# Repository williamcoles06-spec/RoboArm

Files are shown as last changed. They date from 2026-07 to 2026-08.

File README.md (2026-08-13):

# RoboArm

A 6-DOF robot arm I designed and built from scratch, running on a ROS 2 / MoveIt 2 stack.

## What this is

Six joints, each driven by a stepper motor with a custom gearbox: 27:1 cycloidal drives for the base, shoulder, and elbow, a 5:1 planetary drive for the forearm roll, and a 6:1 belt reduction into a bevel gear differential for the wrist pitch and roll. The structure is 3D printed in PLA, designed in Fusion 360.

Motion planning goes through MoveIt 2, but the hardware interface underneath it is custom. The stepper controllers (CANBUS Stepper boards, closed loop, daisy chained over CAN) don't fit cleanly into `ros2_control` on this setup, so I wrote a standalone ROS 2 node that acts as the `FollowJointTrajectory` action server MoveIt talks to directly. It turns planned trajectories into CAN bus position commands, verifies the arm actually reached each target using live encoder feedback, and publishes `/joint_states` back to MoveIt.

## Highlights

- Full 6-DOF planning through MoveIt 2, including a differential wrist where two motors jointly produce pitch and roll (no 1:1 joint-to-motor mapping)
- A custom hardware driver that bypasses `ros2_control` entirely, with arrival verification instead of just trusting planned timing
- A companion desktop app for building and running multi-waypoint motion sequences: drag the arm into a pose in RViz, capture it as a waypoint, set a speed and pause time for that segment, and save the whole sequence under a name to reuse later
- One click to start everything: attach the hardware, launch RViz, and open the sequencer together

## Repo layout

- `robo_arm_simplified_for_urdf_v2_1/` - URDF and mesh files, exported from Onshape
- `robo_arm_moveit_config/` - MoveIt 2 configuration: kinematics, joint limits, planning pipeline, launch files
- `arm_driver/` - the hardware driver (`canbus_bridge.py`), the CANBUS Stepper protocol library, the waypoint sequencer GUI, and one-off hardware diagnostic scripts under `diagnostics/`
- `Robo Arm Assembly.step` - the full CAD assembly

## Hardware

| Joint | Function | Reduction | Motor |
|---|---|---|---|
| J1 | Base rotation | 27:1 cycloidal | 38 mm NEMA 17 |
| J2 | Shoulder | 27:1 cycloidal | 60 mm NEMA 17 |
| J3 | Elbow | 27:1 cycloidal | 48 mm NEMA 17 |
| J4 | Forearm roll | 5:1 planetary | 38 mm NEMA 17 |
| J5 / J6 | Wrist pitch / roll | 6:1 belt into bevel gear differential | 2x 23mm Nema 17 |

Each joint runs on a [CANBUS Stepper](https://thingsbyjosh.com) controller board (ESP32-S3, TMC2209 driver, closed-loop magnetic encoder), all chained on a single CAN bus reachable over one USB-C connection.

## Software

ROS 2 Jazzy and MoveIt 2. No `ros2_control` - `arm_driver/canbus_bridge.py` talks directly to MoveIt as the trajectory execution interface.

## Status

Fully working end to end: homing and calibration on all 6 joints, MoveIt Plan and Execute, and multi-waypoint sequences through the companion GUI.

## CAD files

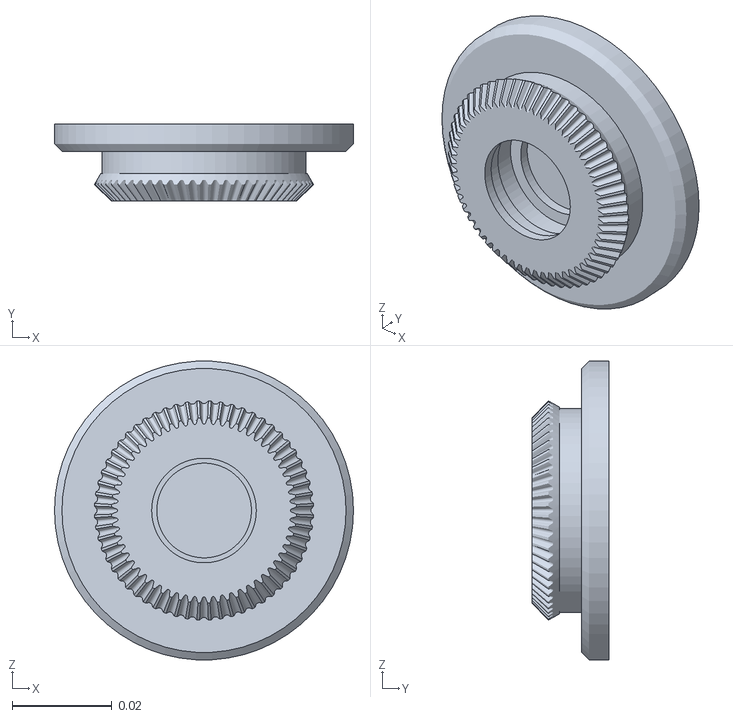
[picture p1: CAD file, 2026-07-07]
robo_arm_simplified_for_urdf_v2_1/meshes/Link_6.stl
0.06 x 0.0155 x 0.0599

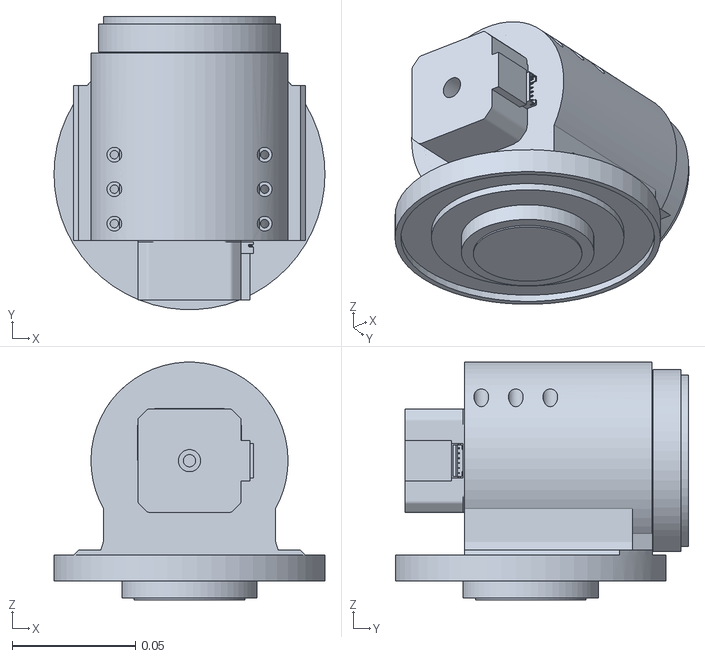
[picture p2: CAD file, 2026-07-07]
robo_arm_simplified_for_urdf_v2_1/meshes/Link_1.stl
0.11 x 0.119 x 0.0964

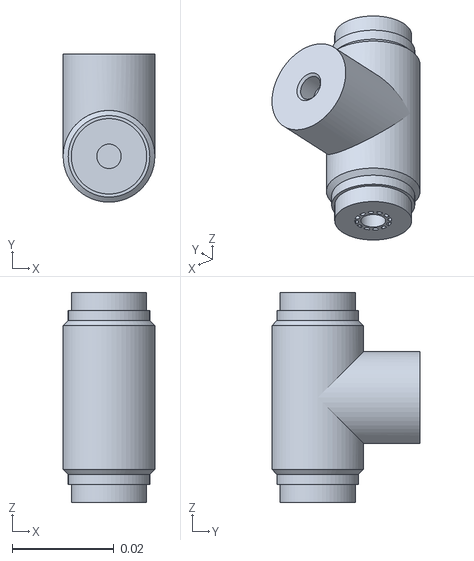
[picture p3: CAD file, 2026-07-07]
robo_arm_simplified_for_urdf_v2_1/meshes/Link_5.stl
0.018 x 0.0291 x 0.0412

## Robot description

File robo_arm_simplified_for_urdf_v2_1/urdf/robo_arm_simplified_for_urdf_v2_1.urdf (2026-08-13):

<?xml version='1.0' encoding='utf-8'?>
<robot name="robo_arm_simplified_for_urdf_v2_1">
    <link name="link_0">
        <inertial>
            <mass value="2.0" />
            <origin xyz="-0.000294655 -1.03725e-07 0.0201983" rpy="0 -0 0" />
            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
        </inertial>
        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</link>
    <link name="link_1">
        <inertial>
            <mass value="1.5" />
            <origin xyz="4.68366e-05 0.00706407 0.0362116" rpy="0 -0 0" />
            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
        </inertial>
        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</link>
    <link name="link_2">
        <inertial>
            <mass value="1.2" />
            <origin xyz="2.62802e-09 0.0144737 0.13931" rpy="0 -0 0" />
            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
        </inertial>
        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</link>
    <link name="link_3">
        <inertial>
            <mass value="0.8" />
            <origin xyz="0.000116996 -0.0362078 -0.00999308" rpy="0 -0 0" />
            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
        </inertial>
        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</link>
    <link name="link_4">
        <inertial>
            <mass value="0.5" />
            <origin xyz="-0.000557991 0.0653842 -5.2404e-06" rpy="0 -0 0" />
            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
        </inertial>
        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</link>
    <link name="link_5">
        <inertial>
            <mass value="0.3" />
            <origin xyz="3.27047e-12 0.00336436 -0.0170378" rpy="0 -0 0" />
            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
        </inertial>
        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</link>
    <link name="link_6">
        <inertial>
            <mass value="0.2" />
            <origin xyz="-6.47991e-07 0.00784846 -7.47187e-09" rpy="0 -0 0" />
            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
        </inertial>
        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</link>
    <link name="mate_connector_1">
        <inertial>
            <mass value="1e-09" />
            <origin xyz="0 0 0" rpy="0 -0 0" />
            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
        </inertial>
    </link>
    <link name="mate_connector_2">
        <inertial>
            <mass value="1e-09" />
            <origin xyz="0 0 0" rpy="0 -0 0" />
            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
        </inertial>
    </link>
    <link name="mate_connector_3">
        <inertial>
            <mass value="1e-09" />
            <origin xyz="0 0 0" rpy="0 -0 0" />
            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
        </inertial>
    </link>
    <link name="mate_connector_4">
        <inertial>
            <mass value="1e-09" />
            <origin xyz="0 0 0" rpy="0 -0 0" />
            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
        </inertial>
    </link>
    <link name="root" />
    <joint name="fixed_node_to_root_joint" type="fixed">
        <origin xyz="0 0 0" rpy="0 -0 0" />
        <axis xyz="0 0 1" />
        <parent link="root" />
        <child link="link_0" />
    </joint>
    <joint name="mate_connector_1" type="fixed">
        <origin xyz="0 0 0" rpy="0 1.57917e-60 0" />
        <axis xyz="0 0 1" />
        <parent link="link_5" />
        <child link="mate_connector_1" />
    </joint>
    <joint name="mate_connector_2" type="fixed">
        <origin xyz="2.6168e-05 0.1245 0.0171007" rpy="3.14159 -3.96548e-61 0" />
        <axis xyz="0 0 1" />
        <parent link="link_4" />
        <child link="mate_connector_2" />
    </joint>
    <joint name="mate_connector_3" type="fixed">
        <origin xyz="0 0 0" rpy="-1.5708 0 0" />
        <axis xyz="0 0 1" />
        <parent link="link_3" />
        <child link="mate_connector_3" />
    </joint>
    <joint name="mate_connector_4" type="fixed">
        <origin xyz="-1.21353e-15 -0.0249798 0.24" rpy="1.5708 -0 0" />
        <axis xyz="0 0 1" />
        <parent link="link_2" />
        <child link="mate_connector_4" />
    </joint>
    <joint name="revolute_1" type="revolute">
        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
        <origin xyz="-1.49235e-17 7.11621e-24 0.1037" rpy="0 0 -1.570796" />
        <axis xyz="-0 -0 -1" />
        <parent link="link_0" />
        <child link="link_1" />
        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
        <limit effort="1" velocity="1" lower="-2.356194" upper="3.665191" />
    </joint>
    <joint name="revolute_2" type="revolute">
        <origin xyz="7.79295e-18 0.0640254 0.0457749" rpy="0 -0 0" />
        <axis xyz="-0 -1 -0" />
        <parent link="link_1" />
        <child link="link_2" />
        <limit effort="1" velocity="1" lower="-1.91986" upper="1.91986" />
    </joint>
    <joint name="revolute_3" type="revolute">
        <origin xyz="3.93793e-17 -0.0249798 0.24" rpy="0 -0 0" />
        <axis xyz="-0 1 -0" />
        <parent link="link_2" />
        <child link="link_3" />
        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
        <limit effort="1" velocity="1" lower="-0.785398" upper="7.068583" />
    </joint>
    <joint name="revolute_4" type="revolute">
        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
        <origin xyz="3.9942e-16 -0.0404996 0.0353704" rpy="1.570796 0 -1.570796" />
        <axis xyz="-0 -1 -0" />
        <parent link="link_3" />
        <child link="link_4" />
        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
        <limit effort="1" velocity="1" lower="-3.141593" upper="3.141593" />
    </joint>
    <joint name="revolute_5" type="revolute">
        <origin xyz="2.6168e-05 0.1245 0.0171007" rpy="-8.03191e-32 3.96004e-63 9.86076e-32" />
        <axis xyz="-0 -0 1" />
        <parent link="link_4" />
        <child link="link_5" />
        <limit effort="1" velocity="1" lower="-1.5708" upper="1.5708" />
    </joint>
    <joint name="revolute_6" type="revolute">
        <origin xyz="1.12164e-16 0.0201 -0.0171007" rpy="-7.61227e-32 1.06671e-76 2.8026e-45" />
        <axis xyz="-0 -1 -0" />
        <parent link="link_5" />
        <child link="link_6" />
        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
        <limit effort="1" velocity="1" lower="-3.141593" upper="3.141593" />
    </joint>
</robot>

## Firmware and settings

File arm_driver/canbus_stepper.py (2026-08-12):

"""

thingsbyjosh.com

Python interface for the CANBUS Stepper Motor Controllers over USB serial.

Protocol overview:
  - 11-bit CAN Standard ID encodes NodeID (5 bits) and MsgType (6 bits)
  - CAN_ID = (NodeID << 6) | MsgType
  - Serial frame: "<CAN_ID_hex> <RTR> <payload_16hex_chars>\n"
  - All multi-byte values are little-endian
  - NodeID 0 = broadcast to all nodes

Example usage: (see bottom of page for actual code example)
    bus = CANBus("COM3")

    node1 = bus.node(1)
    node1.set_position(360.0)
    node1.set_velocity(90.0)
    node1.enable()

    # Broadcast to all nodes
    bus.broadcast.estop()

    # Request telemetry
    angle = node1.get_angle()
    voltage = node1.get_voltage()

    bus.close()
"""

import struct
import threading
import time
from collections import defaultdict
from typing import Callable, Dict, Optional

import serial


# ---------------------------------------------------------------------------
# Protocol constants
# ---------------------------------------------------------------------------

BROADCAST_NODE_ID = 0


class MsgType:
    """Command message types (0–31)."""
    NOP                = 0
    SET_POSITION_DEG   = 1
    SET_POSITION_STEPS = 2
    SET_VELOCITY       = 3
    SET_CURRENT        = 4
    ENABLE             = 5
    ESTOP              = 6
    SENSORLESS_HOME    = 7
    ZERO_ON_BOOT       = 8
    LED_STATE          = 9
    STEPS_PER_REV      = 10
    MICROSTEPS         = 11
    STALLGUARD_THRESH  = 12
    CLOSED_LOOP_TYPE   = 13
    STANDSTILL_MODE    = 14
    MAP_DIRECTION      = 15
    POSITION_SPEED     = 16
    ACCELERATION       = 17
    DECELERATION       = 18
    REPORT_FREQUENCY   = 19
    ENABLE_ON_BOOT     = 20
    DISABLE_3V3_LED    = 21
    RESET_TO_DEFAULT   = 23
    SAVE_CONFIG        = 24
    SET_NODE_ID        = 25
    AUX_CONNECTOR      = 26

    """Telemetry message types (32–63)."""
    ENCODER_COUNTS     = 32
    ENCODER_ANGLE_DEG  = 33
    VOLTAGE            = 34
    BUTTON_STATES      = 35
    STALLGUARD_VALUE   = 36
    STALLGUARD_TRIGGER = 37
    BOARD_TEMPERATURE  = 38
    FAULT_CODE         = 39
    SOFTWARE_VERSION   = 40
    ESP32_TEMPERATURE  = 41
    CURRENT_VELOCITY   = 42


class StandstillMode:
    NORMAL         = 0
    FREEWHEELING   = 1
    BRAKING        = 2
    STRONG_BRAKING = 3


class AuxFunction:
    DISABLED       = 0
    SERIAL_CONTROL = 1
    DIGITAL_OUTPUT = 3
    DIGITAL_INPUT  = 4
    ANALOG_INPUT   = 5
    PWM_OUTPUT     = 6


# ---------------------------------------------------------------------------
# Frame encoding / decoding
# ---------------------------------------------------------------------------

def build_can_id(node_id: int, msg_type: int) -> int:
    return (node_id << 6) | msg_type


def parse_can_id(can_id: int):
    """Returns (node_id, msg_type)."""
    return (can_id >> 6) & 0x1F, can_id & 0x3F


def encode_frame(node_id: int, msg_type: int, rtr: int, payload: bytes) -> bytes:
    """
    Encode a serial frame.
    Format: "<CAN_ID_hex> <RTR> <payload_16hex>\n"
    Payload is always zero-padded to 8 bytes.
    """
    can_id = build_can_id(node_id, msg_type)
    padded = payload.ljust(8, b'\x00')[:8]
    frame = f"{can_id:X} {rtr} {padded.hex().upper()}\n"
    return frame.encode()


def decode_frame(line: str):
    """
    Decode a serial frame string.
    Returns (node_id, msg_type, rtr, payload_bytes) or None on error.
    """
    parts = line.strip().split()
    if len(parts) != 3:
        return None
    try:
        can_id = int(parts[0], 16)
        rtr    = int(parts[1])
        payload = bytes.fromhex(parts[2])
        node_id, msg_type = parse_can_id(can_id)
        return node_id, msg_type, rtr, payload
    except (ValueError, AttributeError):
        return None


# ---------------------------------------------------------------------------
# CANBus — serial connection + receive loop
# ---------------------------------------------------------------------------

class CANBus:
    """
    Manages the serial connection to a CANBUS stepper network.

    Args:
        port:     Serial port, e.g. "COM3" or "COM12"
        baudrate: Serial baud rate (default 115200)
        timeout:  Serial read timeout in seconds
    """

    def __init__(self, port: str, baudrate: int = 115200, timeout: float = 0.1):
        self._ser = serial.Serial(port, baudrate=baudrate, timeout=timeout)
        self._lock = threading.Lock()

        # Registered callbacks: {(node_id, msg_type): [callable, ...]}
        self._callbacks: Dict[tuple, list] = defaultdict(list)

        # One-shot response events for RTR requests: {(node_id, msg_type): threading.Event}
        self._pending: Dict[tuple, dict] = {}
        self._pending_lock = threading.Lock()

        self._running = True
        self._rx_thread = threading.Thread(target=self._rx_loop, daemon=True)
        self._rx_thread.start()

        # Expose a broadcast node
        self.broadcast = StepperNode(self, BROADCAST_NODE_ID)

    # -- Public API ----------------------------------------------------------

    def node(self, node_id: int) -> "StepperNode":
        """Get a StepperNode handle for the given node_id (1–31)."""
        if not 1 <= node_id <= 31:
            raise ValueError(f"node_id must be 1–31, got {node_id}")
        return StepperNode(self, node_id)

    def on_telemetry(self, node_id: int, msg_type: int, callback: Callable):
        """
        Register a callback for incoming telemetry frames.
        callback(node_id, msg_type, payload_bytes)
        """
        self._callbacks[(node_id, msg_type)].append(callback)

    def close(self):
        self._running = False
        self._rx_thread.join(timeout=1.0)
        self._ser.close()

    # -- Internal ------------------------------------------------------------

    def _send(self, node_id: int, msg_type: int, rtr: int, payload: bytes):
        frame = encode_frame(node_id, msg_type, rtr, payload)
        with self._lock:
            self._ser.write(frame)

    def _request(self, node_id: int, msg_type: int, timeout: float = 1.0):
        """Send an RTR request and block until the response arrives."""
        key = (node_id, msg_type)
        event = threading.Event()
        result = {}

        with self._pending_lock:
            self._pending[key] = {"event": event, "result": result}

        self._send(node_id, msg_type, rtr=1, payload=b'\x00' * 8)

        if not event.wait(timeout):
            with self._pending_lock:
                self._pending.pop(key, None)
            raise TimeoutError(
                f"No response from node {node_id} for msg_type {msg_type}"
            )

        return result.get("payload")

    def _rx_loop(self):
        while self._running:
            try:
                raw = self._ser.readline()
                if not raw:
                    continue
                line = raw.decode(errors="replace")
                parsed = decode_frame(line)
                if parsed is None:
                    continue

                node_id, msg_type, rtr, payload = parsed

                # Resolve any pending RTR request
                key = (node_id, msg_type)
                with self._pending_lock:
                    pending = self._pending.pop(key, None)
                if pending:
                    pending["result"]["payload"] = payload
                    pending["event"].set()

                # Fire registered callbacks
                for cb in self._callbacks.get(key, []):
                    try:
                        cb(node_id, msg_type, payload)
                    except Exception as e:
                        print(f"[canbus] callback error: {e}")

            except Exception:
                pass

    def __enter__(self):
        return self

    def __exit__(self, *_):
        self.close()


# ---------------------------------------------------------------------------
# StepperNode — per-node command and telemetry API
# ---------------------------------------------------------------------------

class StepperNode:
    """
    High-level interface for a single CANBUS stepper node.

    All send methods return self to allow chaining, e.g.:
        node1.set_acceleration(500).set_position(180)
    """

    def __init__(self, bus: CANBus, node_id: int):
        self._bus = bus
        self.node_id = node_id

    # -- Convenience ---------------------------------------------------------

    def _send(self, msg_type: int, payload: bytes = b''):
        self._bus._send(self.node_id, msg_type, rtr=0, payload=payload)
        return self

    def _request(self, msg_type: int, timeout: float = 1.0) -> bytes:
        return self._bus._request(self.node_id, msg_type, timeout=timeout)

    # -- Motion commands -----------------------------------------------------

    def set_position(self, degrees: float):
        """Move to an absolute position in degrees (64-bit double)."""
        payload = struct.pack("<d", float(degrees))
        return self._send(MsgType.SET_POSITION_DEG, payload)

    def set_position_steps(self, steps: int):
        """Move to an absolute position in steps (64-bit signed int)."""
        payload = struct.pack("<q", int(steps))
        return self._send(MsgType.SET_POSITION_STEPS, payload)

    def set_velocity(self, deg_per_sec: float):
        """Set continuous velocity in deg/sec (32-bit float)."""
        payload = struct.pack("<f", float(deg_per_sec))
        return self._send(MsgType.SET_VELOCITY, payload)

    def set_position_speed(self, deg_per_sec: float):
        """Set the max speed used during position moves (deg/sec)."""
        payload = struct.pack("<f", float(deg_per_sec))
        return self._send(MsgType.POSITION_SPEED, payload)

    def set_acceleration(self, deg_per_sec2: float):
        """Set acceleration (deg/sec²)."""
        payload = struct.pack("<f", float(deg_per_sec2))
        return self._send(MsgType.ACCELERATION, payload)

    def set_deceleration(self, deg_per_sec2: float):
        """Set deceleration (deg/sec²)."""
        payload = struct.pack("<f", float(deg_per_sec2))
        return self._send(MsgType.DECELERATION, payload)

    # -- Motor state ---------------------------------------------------------

    def enable(self):
        """Enable the motor driver."""
        return self._send(MsgType.ENABLE, struct.pack("<B", 1))

    def disable(self):
        """Disable the motor driver."""
        return self._send(MsgType.ENABLE, struct.pack("<B", 0))

    def estop(self):
        """Immediately stop the motor (emergency stop)."""
        return self._send(MsgType.ESTOP)

    def nop(self):
        """Send a no-op / keep-alive frame."""
        return self._send(MsgType.NOP)

    # -- Configuration -------------------------------------------------------

    def set_current(self, percent: int):
        """Set motor current as a percentage (0–100)."""
        if not 0 <= percent <= 100:
            raise ValueError("Current must be 0–100%")
        payload = struct.pack("<H", int(percent))
        return self._send(MsgType.SET_CURRENT, payload)

    def set_microsteps(self, microsteps: int):
        """Set microstepping value (e.g. 1, 2, 4, 8, 16, 32, 64, 128, 256)."""
        payload = struct.pack("<H", int(microsteps))
        return self._send(MsgType.MICROSTEPS, payload)

    def set_steps_per_rev(self, steps: int):
        """Set full steps per revolution (default 200)."""
        payload = struct.pack("<H", int(steps))
        return self._send(MsgType.STEPS_PER_REV, payload)

    def set_closed_loop(self, enabled: bool = True):
        """Enable (True) or disable (False) closed-loop control."""
        payload = struct.pack("<h", 1 if enabled else 0)
        return self._send(MsgType.CLOSED_LOOP_TYPE, payload)

    def set_standstill_mode(self, mode: int = StandstillMode.NORMAL):
        """Set standstill mode. Use StandstillMode constants."""
        payload = struct.pack("<H", int(mode))
        return self._send(MsgType.STANDSTILL_MODE, payload)

    def set_direction(self, inverted: bool = False):
        """Set motor direction. True = inverted."""
        payload = struct.pack("<B", 1 if inverted else 0)
        return self._send(MsgType.MAP_DIRECTION, payload)

    def set_zero_on_boot(self, enabled: bool = True):
        """Set whether the encoder position is zeroed on boot."""
        payload = struct.pack("<B", 1 if enabled else 0)
        return self._send(MsgType.ZERO_ON_BOOT, payload)

    def set_enable_on_boot(self, enabled: bool = True):
        """Set whether the motor is enabled on power-on."""
        payload = struct.pack("<B", 1 if enabled else 0)
        return self._send(MsgType.ENABLE_ON_BOOT, payload)

    def set_report_frequency(self, angle_hz: int = 10, other_hz: int = 1):
        """Set telemetry report rates. 0 disables that telemetry stream."""
        payload = struct.pack("<HH", int(angle_hz), int(other_hz))
        return self._send(MsgType.REPORT_FREQUENCY, payload)

    def set_stallguard_threshold(self, threshold: int):
        """Set the stallguard detection threshold (int16)."""
        payload = struct.pack("<h", int(threshold))
        return self._send(MsgType.STALLGUARD_THRESH, payload)

    def set_led(self, led1: int, led2: int):
        """Control onboard LEDs (0 = off, 1 = on)."""
        payload = struct.pack("<BB", int(led1), int(led2))
        return self._send(MsgType.LED_STATE, payload)

    def sensorless_home(self, direction: int = 1):
        """Trigger sensorless homing. direction: 0 = negative, 1 = positive."""
        payload = struct.pack("<B", int(direction))
        return self._send(MsgType.SENSORLESS_HOME, payload)

    def save_config(self):
        """Save current configuration to non-volatile memory."""
        return self._send(MsgType.SAVE_CONFIG)

    def reset_to_default(self):
        """Restore node to default configuration."""
        return self._send(MsgType.RESET_TO_DEFAULT)

    # -- AUX connector -------------------------------------------------------

    def set_aux(
        self,
        aux1_function: int = AuxFunction.DISABLED,
        aux1_value: int = 0,
        aux2_function: int = AuxFunction.DISABLED,
        aux2_value: int = 0,
    ):
        """
        Configure the AUX connector pins.

        Example — AUX1 PWM 50%, AUX2 digital output HIGH:
            node.set_aux(AuxFunction.PWM_OUTPUT, 2048,
                         AuxFunction.DIGITAL_OUTPUT, 1)
        """
        payload = struct.pack("<HHHH",
            aux1_function, aux1_value,
            aux2_function, aux2_value,
        )
        return self._send(MsgType.AUX_CONNECTOR, payload)

    def set_aux_serial(self):
        """Enable hardware serial control on the AUX connector (both pins)."""
        return self.set_aux(
            AuxFunction.SERIAL_CONTROL, 0,
            AuxFunction.SERIAL_CONTROL, 0,
        )

    # -- Telemetry (RTR requests) --------------------------------------------

    def get_angle(self, timeout: float = 1.0) -> float:
        """Request and return current encoder angle in degrees."""
        payload = self._request(MsgType.ENCODER_ANGLE_DEG, timeout)
        return struct.unpack("<d", payload[:8])[0]

    def get_encoder_counts(self, timeout: float = 1.0) -> int:
        """Request and return raw encoder counts (int64)."""
        payload = self._request(MsgType.ENCODER_COUNTS, timeout)
        return struct.unpack("<q", payload[:8])[0]

    def get_voltage(self, timeout: float = 1.0) -> float:
        """Request and return bus voltage in volts."""
        payload = self._request(MsgType.VOLTAGE, timeout)
        return struct.unpack("<f", payload[:4])[0]

    def get_board_temperature(self, timeout: float = 1.0) -> float:
        """Request and return PCB temperature in °C."""
        payload = self._request(MsgType.BOARD_TEMPERATURE, timeout)
        return struct.unpack("<f", payload[:4])[0]

    def get_esp32_temperature(self, timeout: float = 1.0) -> float:
        """Request and return ESP32 internal temperature in °C."""
        payload = self._request(MsgType.ESP32_TEMPERATURE, timeout)
        return struct.unpack("<f", payload[:4])[0]

    def get_velocity(self, timeout: float = 1.0) -> float:
        """Request and return current velocity in deg/sec."""
        payload = self._request(MsgType.CURRENT_VELOCITY, timeout)
        return struct.unpack("<f", payload[:4])[0]

    def get_software_version(self, timeout: float = 1.0) -> float:
        """Request and return firmware version."""
        payload = self._request(MsgType.SOFTWARE_VERSION, timeout)
        return struct.unpack("<f", payload[:4])[0]

    def get_aux_states(self, timeout: float = 1.0) -> bytes:
        """Request and return AUX pin states (raw 8-byte payload)."""
        return self._request(MsgType.AUX_CONNECTOR, timeout)

    def get_microsteps(self, timeout: float = 1.0) -> int:
        """Request current microstepping setting."""
        payload = self._request(MsgType.MICROSTEPS, timeout)
        return struct.unpack("<H", payload[:2])[0]

    def get_current(self, timeout: float = 1.0) -> int:
        """Request current motor current setting (%)."""
        payload = self._request(MsgType.SET_CURRENT, timeout)
        return struct.unpack("<H", payload[:2])[0]

    def __repr__(self):
        label = "broadcast" if self.node_id == 0 else f"node_id={self.node_id}"
        return f"<StepperNode {label}>"


# ---------------------------------------------------------------------------
# Example usage
# ---------------------------------------------------------------------------

if __name__ == "__main__":
    PORT = "COM374"  # adjust to your COM port (check Device Manager)

    with CANBus(PORT) as bus:
        node1 = bus.node(1)
        node2 = bus.node(2)

        # Register a callback for continuous angle telemetry from node 1
        def on_angle(node_id, msg_type, payload):
            angle = struct.unpack("<d", payload[:8])[0]
            print(f"[telemetry] node {node_id} angle: {angle:.2f}°")

        bus.on_telemetry(1, MsgType.ENCODER_ANGLE_DEG, on_angle)

        # Configure node 1
        node1.set_microsteps(16)
        node1.set_current(40)
        node1.set_acceleration(720.0)
        node1.set_deceleration(720.0)
        node1.set_position_speed(360.0)
        node1.save_config()

        # Enable and move
        node1.enable()
        node1.set_position(180.0)
        time.sleep(2.0)
        node1.set_position(0.0)
        time.sleep(2.0)

        # Request telemetry
        try:
            angle   = node1.get_angle()
            voltage = node1.get_voltage()
            temp    = node1.get_board_temperature()
            version = node1.get_software_version()
            print(f"Angle:       {angle:.2f}°")
            print(f"Voltage:     {voltage:.2f} V")
            print(f"Temperature: {temp:.1f} °C")
            print(f"FW Version:  {version:.2f}")
        except TimeoutError as e:
            print(f"Telemetry timeout: {e}")

        # Broadcast emergency stop to all nodes
        bus.broadcast.estop()

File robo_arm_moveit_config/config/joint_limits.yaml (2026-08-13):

# Position limits: from ROBOT_ARM_HANDOFF.md §3 (protect the wiring looms).
# Velocity limits: derived from the flashed per-board speed ceiling (§3), converted
# through each joint's gear ratio so MoveIt never plans motion the hardware can't
# execute. J1-J3 ratio 27:1, J4 ratio 5:1, both capped at the flashed 1600 motor-deg/s.
# J5/J6 (wrist) are a differential (§6): the conservative bound below keeps BOTH motors
# under their flashed 6400 motor-deg/s ceiling even if pitch and roll move at once.
default_velocity_scaling_factor: 0.1
default_acceleration_scaling_factor: 0.1
joint_limits:
  revolute_1:
    has_position_limits: true
    min_position: -2.356194   # -135 deg (asymmetric wiring limit, same as J3)
    max_position: 3.665191    # +210 deg
    has_velocity_limits: true
    max_velocity: 1.034439    # 1600 motor-deg/s / 27
    has_acceleration_limits: true
    max_acceleration: 4.0
  revolute_2:
    has_position_limits: true
    min_position: -1.570796   # -90 deg
    max_position: 1.570796    # +90 deg
    has_velocity_limits: true
    max_velocity: 1.034439    # 1600 motor-deg/s / 27
    has_acceleration_limits: true
    max_acceleration: 4.0
  revolute_3:
    has_position_limits: true
    min_position: -0.785398   # -45 deg (asymmetric about home)
    max_position: 7.068583    # +405 deg
    has_velocity_limits: true
    max_velocity: 1.034439    # 1600 motor-deg/s / 27
    has_acceleration_limits: true
    max_acceleration: 4.0
  revolute_4:
    has_position_limits: true
    min_position: -3.141593   # -180 deg
    max_position: 3.141593    # +180 deg
    has_velocity_limits: true
    max_velocity: 5.585054    # 1600 motor-deg/s / 5
    has_acceleration_limits: true
    max_acceleration: 4.0
  revolute_5:
    has_position_limits: true
    min_position: -1.570796   # -90 deg pitch
    max_position: 1.570796    # +90 deg pitch
    has_velocity_limits: true
    max_velocity: 9.308997    # 6400 motor-deg/s / (2 * R=6)
    has_acceleration_limits: true
    max_acceleration: 4.0
  revolute_6:
    has_position_limits: true
    min_position: -3.141593   # -180 deg roll
    max_position: 3.141593    # +180 deg roll
    has_velocity_limits: true
    max_velocity: 9.308997    # 6400 motor-deg/s / (2 * R=6)
    has_acceleration_limits: true
    max_acceleration: 4.0

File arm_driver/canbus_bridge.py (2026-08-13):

#!/usr/bin/env python3
"""
CANBUS Stepper <-> ROS 2 bridge and robot driver.

This node replaces ros2_control entirely (see ROBOT_ARM_HANDOFF.md §7): it is
a FollowJointTrajectory action server that MoveIt talks to directly, plus a
/joint_states publisher built from live encoder telemetry. No ros2_control,
no hardware plugin, no controller spawners.

Five parts, in the order they appear below:
 1. CONFIG            - per-joint node id, gear ratio, direction sign, home
                         encoder angle, and joint limit (§3). Edit values
                         here, never the logic below.
 2. CONVERSIONS        - joint-radians <-> motor-degrees math (§6), shared by
                         the startup sequence, the state publisher, and the
                         action server.
 3. STARTUP SEQUENCE  - §5: the zero-error handoff from "limp at an unknown
                         pose" to "enabled and sitting at true home".
 4. STATE PATH        - a 30 Hz timer reads every board's encoder and
                         publishes /joint_states in joint-space radians.
 5. ACTION SERVER     - FollowJointTrajectory, named to match
                         moveit_controllers.yaml. This is the only interface
                         MoveIt needs; it does not require ros2_control.
"""
import math
import threading
import time

import rclpy
from rclpy.action import ActionServer, CancelResponse, GoalResponse
from rclpy.callback_groups import MutuallyExclusiveCallbackGroup, ReentrantCallbackGroup
from rclpy.executors import MultiThreadedExecutor
from rclpy.node import Node

from control_msgs.action import FollowJointTrajectory
from sensor_msgs.msg import JointState

from canbus_stepper import CANBus

SERIAL_PORT = "/dev/ttyACM0"
ACTION_NAME = "arm_controller"   # must match moveit_controllers.yaml
STATE_RATE_HZ = 30.0

# Homing creep (§5 step 6) must be slow; flashed operating speed (§3) is not
# safe for an unsupervised move of unknown distance. Restored after homing.
HOMING_SPEED_ARM_DEG_S = 100.0
HOMING_SPEED_WRIST_DEG_S = 100.0
NORMAL_SPEED_ARM_DEG_S = 1600.0   # must match the flashed value in §3
NORMAL_SPEED_WRIST_DEG_S = 6400.0
HOMING_SETTLE_S = 3.0             # crude wait for the homing creep to finish

# Arrival verification: execute_trajectory doesn't just trust that the
# commanded time elapsed - it polls the real encoders and confirms they
# actually reached the final commanded point before reporting success. This
# also protects against a trajectory getting silently overridden mid-flight.
ARRIVAL_TOLERANCE_RAD = 0.02
ARRIVAL_TIMEOUT_S = 3.0
ARRIVAL_POLL_INTERVAL_S = 0.1

# MoveIt's time-parameterized trajectories pack in a new waypoint roughly
# every 0.1s. These boards run their own onboard trapezoidal motion profile
# per set_position() command, and redirecting it to a new target every 0.1s
# never gives that profile time to actually accelerate - the arm just
# twitches near its starting point instead of traveling. Downsampling gives
# the board real time to move between updates, while still following the
# same overall path MoveIt validated as collision-free (never skip straight
# from start to the final point - that would throw away the shape of the
# path OMPL used to avoid a collision).
MIN_SEND_INTERVAL_S = 0.5

# ---------------------------------------------------------------------------
# 1. CONFIG - the only place signs/offsets/limits should be edited.
# ---------------------------------------------------------------------------

# J1-J4: simple geared joints. motor_deg = joint_deg * ratio * dir + home_deg
# All values from ROBOT_ARM_HANDOFF.md §3.
JOINTS = {
    # J1: wiring is asymmetric about home, like J3 - real safe range is
    # -135deg to +210deg, not a symmetric +-180.
    "revolute_1": {"node_id": 1, "ratio": 27.0, "dir": 1,
                   "home_deg": -52.65, "min_rad": math.radians(-135), "max_rad": math.radians(210)},
    "revolute_2": {"node_id": 2, "ratio": 27.0, "dir": 1,
                   "home_deg": 236.81, "min_rad": math.radians(-90), "max_rad": math.radians(90)},
    # J3: physical range is -45deg to +405deg, not symmetric about home.
    "revolute_3": {"node_id": 3, "ratio": 27.0, "dir": 1,
                   "home_deg": 180.22, "min_rad": math.radians(-45), "max_rad": math.radians(405)},
    "revolute_4": {"node_id": 4, "ratio": 5.0, "dir": 1,
                   "home_deg": 35.44, "min_rad": math.radians(-180), "max_rad": math.radians(180)},
}

# J5/J6: differential wrist, no 1:1 joint mapping - see §6.
# revolute_5 = pitch (joint radians), revolute_6 = roll (joint radians).
WRIST = {
    "node5_id": 5, "node6_id": 6,
    "home5_deg": 138.83, "home6_deg": -35.89,
    "R": 6.0,
    "s5": 1, "s6": -1,  # same-direction motor motion on both nodes = roll, not pitch
    "pitch_limit_rad": math.radians(90),
    "roll_limit_rad": math.radians(180),
}

ALL_JOINTS = ["revolute_1", "revolute_2", "revolute_3",
              "revolute_4", "revolute_5", "revolute_6"]


# ---------------------------------------------------------------------------
# 2. CONVERSIONS
# ---------------------------------------------------------------------------

def joint_to_motor_deg(cfg, joint_rad):
    return math.degrees(joint_rad) * cfg["ratio"] * cfg["dir"] + cfg["home_deg"]


def motor_to_joint_rad(cfg, motor_deg):
    """The boards report real, multi-revolution-aware absolute position
    directly (not a wrapped single-turn value) - plain offset-then-divide."""
    delta = motor_deg - cfg["home_deg"]
    return math.radians(delta / (cfg["ratio"] * cfg["dir"]))


def wrist_forward(m5_deg, m6_deg):
    """Motor degrees -> (pitch_rad, roll_rad)."""
    d5 = (m5_deg - WRIST["home5_deg"]) * WRIST["s5"]
    d6 = (m6_deg - WRIST["home6_deg"]) * WRIST["s6"]
    pitch = math.radians((d5 + d6) / (2 * WRIST["R"]))
    roll = math.radians((d5 - d6) / (2 * WRIST["R"]))
    return pitch, roll


def wrist_inverse(pitch_rad, roll_rad):
    """(pitch_rad, roll_rad) -> (m5_deg, m6_deg)."""
    pitch_deg = math.degrees(pitch_rad)
    roll_deg = math.degrees(roll_rad)
    m5 = WRIST["home5_deg"] + (pitch_deg + roll_deg) * WRIST["R"] / WRIST["s5"]
    m6 = WRIST["home6_deg"] + (pitch_deg - roll_deg) * WRIST["R"] / WRIST["s6"]
    return m5, m6
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

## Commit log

2026-07-07 Working MoveIt config + URDF for 6-DOF arm
    [Link_1.stl, Link_5.stl, Link_6.stl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]
2026-08-12 Bring up real hardware: standalone FollowJointTrajectory bridge, bypass ros2_control
    ros2_control_node segfaults loading JointTrajectoryController on this setup, so
    canbus_bridge.py is now a standalone ROS 2 node that is itself the robot driver:
    runs the startup/homing sequence, publishes /joint_states from live encoders, and
    serves a FollowJointTrajectory action server that MoveIt talks to directly via
    moveit_simple_controller_manager. demo.launch.py now starts robot_state_publisher +
    move_group + RViz + the bridge, no ros2_control_node or spawners.
    Also fixes found bringing up all 6 joints on real hardware:
    - moveit_controllers.yaml was missing the required action_ns parameter, which
    ma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
    [joint_limits.yaml, robo_arm_simplified_for_urdf_v2_1.ros2_control.xacro, robo_arm_simplified_for_urdf_v2_1.urdf]
2026-08-12 Add multi-waypoint sequencer GUI, fix motion planning bugs found during testing
    - Fix motor_to_joint_rad/wrist_forward: boards report real multi-revolution
    position directly, not a wrapped single-turn value - the old wrap_deg call
    silently corrupted readback (both /joint_states and arrival checks) for any
    joint move bigger than a fraction of a motor revolution
    - Convert revolute_1/3/4/6 from continuous to revolute with real URDF limits -
    continuous joints were planning/interpolating in a wraparound space
    - Correct J1's real safe range to -135/+210deg (asymmetric, wiring constraint)
    - Add config/ompl_planning.yaml: tighten longest_valid_segment_fraction so
    OMPL's search can't hand o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
    [joint_limits.yaml, robo_arm_simplified_for_urdf_v2_1.urdf]
2026-08-13 Add README and CAD assembly, clean up comments for public repo
    - Add README.md describing the project, hardware, software stack, and repo layout
    - Add the full CAD assembly (Robo Arm Assembly.step)
    - Clean up dated debugging-journal style comments across the driver, URDF, and
    MoveIt config into plain engineering documentation
    [joint_limits.yaml, robo_arm_simplified_for_urdf_v2_1.urdf]
2026-08-13 Revise README for clarity and technical accuracy
    Updated descriptions for clarity and accuracy, including changes to the gearbox type and design software.
2026-08-13 Update motor specifications in README.md
2026-08-13 README: precisely describe the wrist as a belt reduction into a bevel gear differential
